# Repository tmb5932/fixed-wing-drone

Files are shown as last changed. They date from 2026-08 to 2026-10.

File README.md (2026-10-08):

# Autonomous RC Plane

A custom flight controller for a fixed-wing RC plane, built from scratch, both the PCB and the firmware. It's built around an ESP32-S3 and runs in-between a standard RC receiver and the servos/esc, giving the plane an onboard brain capable of taking over from the pilot and flying autonomously.

All software is written in ESP-IDF (specifically v5.5). It's a personal challenge to write as much of it as possible without plug-and-play libraries (ESP-IDF's own UART/I2C drivers are fair game), mainly the device drivers and the flight control logic.

## The Goal

The flight control system is a cascade of PID loops: GPS waypoint/heading navigation on the outside, commanding roll/pitch attitude loops on the inside, plus an airspeed loop on the throttle. Target milestones, roughly in order:

- [x] RC pass-through with working sensor drivers (IMU, GPS) and RC I/O
- [x] First flight (manual pass-through, October 3, 2026)
- [ ] Stable autonomous level flight
- [ ] Altitude hold
- [ ] GPS-guided heading / waypoint following (implemented and SITL-tested, not flown yet)
- [ ] Autonomous takeoff and landing

Longer term, the hopes are giving it mission-oriented capabilities like payload release or coordinated flight with a second drone.

## Current Status

The plane had its first flight on October 3, 2026, in manual pass-through mode only. The RC link had signal dropouts during that flight, so that's being debugged before anything autonomous is tried in the air. Since then the firmware has gained an on-board flight event log, a longer signal-loss window, and safer behaviour when the radio drops (see Safety below).

Autonomous mode (attitude stabilization, waypoint following, return-to-home) has only been tested on the bench and in the SITL simulator. The roll/pitch/heading gains come from SITL sweeps and still need real flight tuning.

## Hardware

- ESP32-S3
- ICM-20948 IMU (I2C), roll/pitch/yaw via a Madgwick filter, with its AK09916 magnetometer used for compass heading
- GPS module (UART, NMEA)
- MS4525DO differential-pressure airspeed sensor (I2C)
- Standard PWM RC receiver and servos/ESC, running alongside the ESP32 instead of being replaced by it

Future hardware will hopefully include lidar and a barometer.

### PCB

The firmware currently runs on the **v2.1** board: a custom carrier PCB that an ESP32-S3-DevKitC plugs into. Everything plugs into labeled connectors on the board rather than bare GPIO pins:

- 6 RC receiver inputs (PWM), 6 labeled servo outputs, and primary/secondary ESC signal outputs
- Separate UBEC power inputs for the flight controller and the ESC/servo rail, each with P-FET reverse-polarity protection
- JST-SH (STEMMA QT) connectors for the IMU, the barometer, and a spare QT port for future I2C sensors
- A JST-GH connector for the airspeed sensor, a header for the GPS UART, and connectors for a LIDAR
- An accessory I/O header for things like LEDs, a payload-release servo/relay, etc.
    -   (obviously will require alterations to code, but software is easier to change than hardware is...)

The GPIO-to-connector mapping the firmware uses (CH1_OUT_GPIO etc. in main.c) is defined by the board's pinout, not repeated here.

The KiCad sources in [`kicad/`](kicad) are the **next** revisions, which the firmware hasn't been ported to yet:

- [`kicad/flight-controller/`](kicad/flight-controller): flight controller v3.1, a fully integrated 4-layer board (ESP32-S3 module, ICM-42688-P + BMI088 IMUs, DPS368 barometer, microSD, SBUS/CRSF receiver input, USB-C). Pinout and power details are in [`docs/buses.md`](docs/buses.md), and its design review is in [`kicad/flight-controller/design-review-fixed-wing-drone.md`](kicad/flight-controller/design-review-fixed-wing-drone.md).
- [`kicad/mission-board/`](kicad/mission-board): a second ESP32-S3 payload board (camera, motor drivers, switched outputs, servo driver) that talks to the flight controller over UART.
- [`kicad/uwb-radio-kicad/`](kicad/uwb-radio-kicad): a DWM3000 ultra-wideband radio module for ranging between drones.

## Software Architecture

- **RC input:** 6 channels read via the ESP32-S3's MCPWM capture timers. Interrupt-driven edge timestamping converts rising/falling edges into pulse widths directly, no external library.
- **RC/servo output:** 6 servo channels plus 2 dedicated ESC channels, driven via MCPWM comparators on a 20ms timebase. Input/output channel mapping, per-channel PWM range and reversal are all configurable at runtime.
- **IMU:** ICM-20948 and its AK09916 magnetometer driven with hand-written I2C register reads/writes, fused through a ported Madgwick AHRS filter for roll/pitch/yaw, with a stillness-gated gyro bias calibration at boot.
- **GPS:** UART driver with a hand-written NMEA RMC sentence parser, plus u-blox config commands to quiet down unused sentence types and set a 5Hz fix rate.
- **Airspeed:** MS4525DO driver with a boot-time zero-offset calibration and a low-pass filter on the pressure reading.
- **PID:** a small PID module with integral anti-windup, used for roll, pitch, heading and airspeed.
- **Navigation:** a 10Hz task that steers toward GPS waypoints (or holds the heading the plane had when autonomous engaged) by commanding a bank angle, using the compass heading or, when moving, GPS course over ground.
- **Control loop:** a 100Hz task that reads all RC channels every cycle and switches between manual pass-through and autonomous output based on the mode switch (below 1500us = autonomous), RC signal health and sensor availability.

### Safety

- Autonomous mode is only armed after the mode switch has been seen in manual at least once since boot, and it needs a fresh GPS fix to engage.
- If the RC signal is lost for 1 second, the plane returns to its home point (averaged from GPS at power-on), then spirals down with the motor off. With no GPS fix or no home, it spirals down where it is. If autonomous isn't available at all, it holds the surfaces at trim with the motor off instead of replaying the last stick input.
- After a reboot in the air, manual pass-through comes back first, before anything slow in boot.
- A small flight event log in RTC memory records RC dropouts, signal losses, failsafe transitions and the reset reason of every boot. It survives a reset (not a power cycle) and can be read from setup mode after landing.

### SITL

[`sitl/`](sitl) holds host-side simulators that compile the firmware's own `pid.c` and `gps_math.c` against a simple airframe model, used to tune the attitude and heading gains, with an 80-scenario regression suite. See [`sitl/README.md`](sitl/README.md).

## Build / Flash

Set up ESP-IDF v5.5, then from the project root:

```sh
idf.py build
idf.py flash monitor
```

### Setup mode

Holding the board's BOOT button within 5 seconds of power-on boots into a
setup mode instead of normal flight init: it hosts its own WiFi access point
(`plane-fc-setup` by default) with a local web page for calibrating servo/ESC
PWM ranges and direction, remapping RC/servo channels, capturing trim,
planning the GPS mission, tuning PID gains, setting the airframe mixing mode
and airspeed-hold target, running bench control tests, and reading the flight
event log. Connect to the AP
and browse to `http://192.168.4.1/`. Everything is saved to NVS immediately;
a normal reset (BOOT not held) returns to flight mode with those settings
applied.

## Author

Travis Brown

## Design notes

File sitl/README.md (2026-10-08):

# SITL (software-in-the-loop) for the attitude + nav PIDs

Host-side simulators for tuning `ROLL_PID_CFG` / `PITCH_PID_CFG` (`sitl_sim.exe`) and
`HEADING_PID_CFG` (`nav_sim.exe`) before the plane exists to fly. Both link directly against
`../main/pid.c` and `../main/gps_math.c` — the exact same source files the firmware compiles —
so a gain that behaves well here is a gain that will behave the same way on the real controller.

## Build & run

Requires a host C compiler (this repo's ESP-IDF toolchain is a cross-compiler for the ESP32S3 and
can't build a host executable). On Windows that's MSYS2/mingw-w64 (`mingw32-make`); on macOS/Linux
plain `gcc`/`clang` with `make` works (`make`, `make test`). The binaries are named `.exe` on every
platform.

```sh
cd sitl
mingw32-make
./sitl_sim.exe [k_p] [k_i] [k_d] [duration_s] [initial_disturbance_deg] [--axis=roll|pitch] [--goal=deg] [--i_limit=us] [--noise_deg=stddev] [--servo_rate=deg_per_s] [--seed=n]
python plot.py output.csv     # or: .venv\Scripts\python.exe plot.py output.csv
```

CLI defaults are `k_p=10 k_i=0 k_d=0`, 5s, starting 20° off level, roll axis, goal 0° (i.e. recover
to level — the firmware's only behavior until something calls `set_goal_roll_deg`/`set_goal_pitch_deg`).

Or use `python gui.py` (`.venv\Scripts\python.exe gui.py`) for an interactive version: pick an axis,
enter gains, hit Run, see the plot update immediately, with the previous run kept as a faint
reference line so you can see the effect of a change rather than comparing two separate plot windows
from memory. (The reference line clears when you switch axes — roll and pitch use different plant
dynamics now, so overlaying them wouldn't mean anything.) The noise/servo-rate/seed fields live in
their own "Sensor / actuator realism" group, separate from the tuning fields, since they describe
imperfections in the simulated world rather than the controller itself.

`nav_sim.exe` simulates the outer waypoint-following loop added in `nav.c`: it cascades
`HEADING_PID_CFG` into the same roll-attitude loop as `sitl_sim.exe` (reusing its plant/actuator
model), flying a simple coordinated-turn/flat-earth world model toward one or more waypoints.

```sh
./nav_sim.exe [--target_bearing=deg] [--target_dist_m=m] [--wp=lat,lon (repeatable, overrides target_bearing/dist)] [--start_lat=deg] [--start_lon=deg] [--heading0=deg] [--airspeed=mps] [--duration_s=s] [--heading_kp=] [--heading_ki=] [--heading_kd=] [--heading_ilimit=] [--roll_kp=] [--roll_ki=] [--roll_kd=] [--roll_ilimit=] [--roll_noise_deg=] [--heading_noise_deg=] [--servo_rate=deg_per_s] [--seed=n]
python plot_nav.py nav_output.csv
```

With no `--wp`, it generates a single waypoint at `--target_bearing`/`--target_dist_m` from the
start position, which is usually more convenient for gain-sweeping than hand-picked lat/lon pairs.

`mingw32-make test` builds both binaries and runs `tests/run_tests.py`, an 80-scenario regression
suite against the current firmware gains (clean step responses, noise-robustness sweeps, and
waypoint-mission edge cases) — exits nonzero if anything fails.

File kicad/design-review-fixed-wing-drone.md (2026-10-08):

> **Superseded.** This is the original review of flight controller **v3.0** (2026-09-11), kept for history. Most of its findings were fixed in v3.1 (for example, the ESP32's LDO is now the XC6220 `U4`, and USB-C now has ESD protection). The current review is [`flight-controller/design-review-fixed-wing-drone.md`](flight-controller/design-review-fixed-wing-drone.md), and the current pinout is [`../docs/buses.md`](../docs/buses.md).

# Design Review — Autonomous Fixed-Wing Drone Flight Controller

**Board:** `fixed-wing-drone` v3.0 (4-layer, 91.0 × 61.5 mm, 78 footprints)
**Review date:** 2026-09-11
**Tooling:** kicad-happy analyzer suite (`kicad`, `emc` skills) v2.2.1 + manual raw-file verification
**Reviewer basis:** static analysis + direct `.kicad_sch`/`.kicad_pcb` inspection. **No component datasheets were available** (no `datasheets/` directory, no distributor API keys configured) — see *Verification Basis* below. All pin-level and electrical claims in this report are **consistency checks against the schematic/PCB themselves, not manufacturer-datasheet-verified**, except where explicitly marked "domain knowledge, unverified."

## Verdict: **Conditionally ready — fix 3 items before fab, 1 before flight test**

The board is structurally sound (0 unrouted nets, 4-layer stackup with dedicated ground/power planes, clean gerber export) but has one thermal margin problem serious enough to affect flight reliability, a hard sourcing blocker for ordering, and a stale-file hygiene issue worth resolving before anyone edits this design again. Nothing found is a "board is dead on arrival" bug (no swapped IC pins were found in the ICs checked), but the LDO thermal issue below is not cosmetic — it affects the rail that powers the flight computer itself.

---

## Blockers (fix before fab)

| # | Severity | Finding | Evidence |
|---|---|---|---|
| 1 | **HIGH — thermal/safety** | U5 (AP2112K‑3.3, SOT‑23‑5) regulates 5V→3.3V for the **ESP32‑S3 flight computer's own supply** (`ESP_3V3`). At an assumed WiFi‑active load current, estimated Tj ≈ 124 °C against a 125 °C absolute max — **2 °C margin**. The package has no thermal pad (θJA ≈ 250 °C/W) and a 1.7 V dropout, so *any* sustained current draw above a few tens of mA runs it hot. ESP32‑S3 WiFi TX bursts commonly pull 300–500 mA. | `analysis/2026-09-11_1844/thermal.json` (rule TS‑002); schematic `U5` on `fc_ldo.kicad_sch`/`esp32s3.kicad_sch` net `ESP_3V3`. **Caveat:** the load current behind this estimate is a heuristic default, not a measured/derived figure (schematic power-budget module returned `estimated_load_mA: 0` for this rail — see Gaps below) — so treat 124 °C as directionally right, not exact. Given ESP32-S3's known TX current spikes, this is very plausibly correct or optimistic, not pessimistic. |
| 2 | **HIGH — sourcing (pre-fab gate)** | Only 7 of 30 unique parts (23%) have an MPN populated in the schematic. Rule `SS-001`: "Sourcing blocker: BOM has <50% MPN coverage. Board is not pre-fab ready." **Note:** a separate hand-fabrication BOM exists (`production/FULL_POP_..._bom.csv`) with LCSC part numbers for nearly every part — the gap is that this data lives in a CSV outside the KiCad schematic, not in the symbol properties the analyzer reads. | `analysis/2026-09-11_1844/schematic.json` (`bom_coverage.mpn_pct=21.9`); cross-checked against `production/FULL_POP_Autonomous_Fixed_Wing_FC_v3.0_bom.csv`, which does have LCSC numbers for 27 of the ~30 lines. |
| 3 | **MEDIUM — housekeeping / design-sync risk** | `airspeed.kicad_sch` and `lidar.kicad_sch` exist in the project directory but are **not instantiated anywhere in the sheet hierarchy** — verified by grepping every `.kicad_sch` for `(sheet ...)` includes; neither file is referenced from any reachable sheet. **This is not a missing-sensor bug**: the real, wired design already has airspeed and lidar interfaces — `J15` ("Airspeed I2C") and `J8` ("LIDAR I2C") both live in `external_sensors.kicad_sch`, which *is* in the hierarchy, and both appear in the production BOM/position files. `lidar.kicad_sch`'s components (`J8`, `L2`) are literal duplicates of what's already wired in `external_sensors.kicad_sch`. `airspeed.kicad_sch`'s components (`J12`, `L3`) do **not** appear anywhere in the reachable hierarchy at all — this looks like an earlier on-board-sensor-IC design draft that was superseded by the simpler external-connector approach and never deleted. Recommendation: delete both orphan files, or if there was a reason to move to an on-board airspeed sensor with the `L3` filtering shown in the orphan file, wire it in deliberately. Left as-is, these files will confuse the next person who edits the hierarchy or runs ERC sheet-by-sheet. | `grep -oE '"[a-zA-Z_]+\.kicad_sch"' *.kicad_sch` cross-reference (see transcript); `analysis/2026-09-11_1844/schematic.json` `sheets[]` (11 reachable sheets, excludes airspeed/lidar). |

## Fix before flight test (not fab-blocking)

| # | Severity | Finding | Evidence |
|---|---|---|---|
| 4 | WARNING | **VBUS on J13 (USB‑C) has no decoupling and no ESD/TVS protection.** J13 is marked DNP (hand-solder), but if it's ever populated for field debugging, an unprotected USB‑C VBUS on a vehicle that operates outdoors is a real ESD exposure path into the 5V domain. | `schematic.json` rules `UC-001`, `UC-002`. |
| 5 | WARNING | 18 of 18 external/inter-board connectors (servo I/O, ESC I/O, GPS/UART, I2C sensor headers, SPI, debug headers) show **zero ESD protection** (`EP-AUD`, "none coverage" on all). For a design with cables running out to servos/ESCs/GPS in an airframe subject to field handling and connector mating/unmating, this is worth a deliberate risk decision rather than a silent gap — TVS diodes on at least the RC receiver input (J7) and any GPS/telemetry cable are the highest-value additions. | `schematic.json`, 18× `EP-AUD` findings. |
| 6 | INFO (assess as MEDIUM in practice) | J13 (USB‑C receptacle, 16‑pin **SMD**, fine-pitch) is marked `(dnp yes)` — i.e., intended for hand assembly, not JLCPCB SMT placement. Hand-soldering a 16-pin SMD USB-C receptacle without hot air/reflow is failure-prone (bridged VBUS/GND shield pins, tombstoned shield tabs). All the *other* DNP parts (J1–J9, J16, J19, J20, J22 — the servo/ESC/UBEC pin headers, and J7 the RC receiver connector) are through-hole 3‑pin headers, where DNP-for-hand-solder is completely normal/expected. J13 is the odd one out. Confirm this is intentional. | Raw `esp32s3.kicad_sch:3529-3537` — `(dnp yes)(in_bom yes)(on_board yes)` on the `USB_C_Receptacle_USB2.0_16P` symbol; cross-checked against `production/*_desig.csv` (J13 present, position-only) vs `*_bom.csv` (J13 absent — no LCSC part ordered for it). |
| 7 | WARNING (EMC) | EMC pre-compliance risk score **52/100** (moderate-high). Drivers: low ground-plane fill ratio (F.Cu 49%, B.Cu 44% — confirmed directly from zone fill data, not just the EMC heuristic), missing stitching vias at ~20+ signal layer transitions (SPI/I2C/UART buses to the IMUs, barometer, SD card, UWB radio, inter‑ESP link), SCK routed on an outer layer near connectors J10/J15, and one connector (J13) with no local filtering. See EMC section below. | `analysis/2026-09-11_1844/emc.json`; `pcb.json` zones (fill_ratio 0.494/0.441 for GND on F.Cu/B.Cu). |
| 8 | INFO | PCB has an **unfilled zone on net 0** ("no net") spanning all 4 copper layers (`is_filled: false`, no `fill_ratio`). If this is a deliberate keepout/rule area, fine; if it's a stale zone from editing, refill or delete it — stale zone fill data also means any "copper presence" analysis over that area is unreliable until refilled. | `pcb.json` `zones[]` entry with `net=0`, all layers, `is_filled=false`. |

## Positive findings (verified directly, not just "no finding raised")

- **Routing is complete**: 0 unrouted nets across 84 nets, 632 track segments, 178 vias on a 4-layer stack.
- **Custom DRC rule exists and is architecturally sound**: `fixed-wing-drone.kicad_dru` enforces ≥2mm clearance between `/FC_5V` (flight-computer power) and `/actuator_io/esc_io/SERVO_5V` (servo power) — a deliberate isolation choice so servo-current transients/brownouts don't couple into the FC's own supply. Verified both nets do have separate zone polygons on the shared `In2.Cu` (Pwr.Cu) inner layer as the rule implies. **Not independently verified**: actual DRC pass/fail against this rule — `kicad-cli` is not installed in this environment, so native DRC could not be run (see Gaps).
- **ESP32-S3 EN (reset) circuit is correctly designed** — I initially flagged this as a possible false-positive-worth-checking because the analyzer's `PU-001` rule reported "U1 pin EN missing pull-up resistor." Direct pin-net trace shows this is a **false positive**: `EN` is pulled up through `R7` (10k) to `ESP_3V3`, decoupled by `C12` (1µF) and `C14` (100nF), with `SW1` (TS‑1088 tactile switch) providing a manual reset-to-GND path — a textbook-correct ESP32 EN circuit. (`esp32s3.kicad_sch`, `ic_pin_analysis` for U1 pin 3.)
- **U3 (backup IMU) INT1–INT4 "missing pull-up" findings are also false positives/non-issues** — direct inspection shows all four interrupt pins are explicitly marked `NO_CONNECT` (deliberately unused), not floating inputs needing a pull-up. The `PU-001` heuristic doesn't distinguish sensor-output interrupt pins from bus inputs; both flagged instances here are noise, not real findings.
- **Gerber export is clean**: extracted and ran the gerber analyzer against the `production/FULL_POP_..._v3.0.zip` package (15 files: 4 copper layers incl. 2 inner planes, both silkscreens, both masks, both paste, edge cuts, PTH/NPTH drill + drill maps) — 0 findings (no missing layers, no alignment issues, no drill classification problems).
- **Component/footprint reconciliation is clean**: 75 schematic components vs 78 PCB footprints; the +3 is fully accounted for by 3 mounting holes (`M2`, no schematic symbol expected) — no unexplained extras.
- **DNP strategy for THT headers is sound**: all pin-header connectors (servo/ESC/UBEC-input, RC receiver) are marked DNP for SMT assembly with position data retained — standard "assembly house places SMD, builder hand-solders THT headers" practice, not a build-blocking omission.

## Power Tree

```
Battery/BEC (off-board) ──> J20 "FC UBEC Input" ──> FC_5V ─┬──> U5 AP2112K-3.3 ──> ESP_3V3 ──> U1 (ESP32-S3-WROOM-1)
                                                              └──> U6 AP2112K-3.3 ──> SENSOR_3V3 ──> U2/U3 (IMUs), U7 (barometer), external sensor headers
Servo/ESC power path: separate SERVO_5V net (2mm-isolated from FC_5V by custom DRC rule), routed to J19/J22 (ESC1/ESC2) and servo connectors via In2.Cu plane
```

- Two identical AP2112K‑3.3 LDOs (U5, U6) in SOT‑23‑5, no thermal pad, both dropping 5V→3.3V (1.7V dropout each). Only U5's rail was flagged by the thermal analyzer (it's carrying the higher-current MCU load); U6's sensor rail load is presumably lower but uses the *same* thermally marginal topology — worth a sanity check on total sensor-rail current (2× IMU + barometer + any bus pull-ups) if more sensors get added later.
- Regulator Vout for both was derived via `fixed_suffix` (deterministic — the "-3.3" in the part number), not a feedback-divider calculation, so this is a solid data point, not a heuristic guess.
- No PG (power-good) signal traced for either regulator — `PS-001` notes PG status is unknown without a datasheet (AP2112K does not have a PG pin per its part family — this is expected/non-issue, but unverified here since no datasheet was pulled).

## EMC Pre-Compliance Summary

Risk score: **52/100** (moderate-high), 55 findings (3 error, 36 warning, 16 info), trust level **low** (0% datasheet-backed — expected, since no datasheets were synced; findings are topology/heuristic-based).

Top drivers, all corroborated against raw PCB data (not just the EMC heuristic layer):
- **GP‑001/GP‑004** — reference-plane gaps under signal traces + low GND fill ratio, confirmed directly (F.Cu GND zone fill 49.4%, B.Cu 44.1%).
- **RP‑001** — 20+ signal nets (SPI to both IMUs/barometer/SD/UWB, I2C, inter-ESP UART, ESP32 BOOT strap) change layers without a nearby stitching via, weakening return-path continuity — this is the largest single finding category and the most actionable (add stitching vias near layer transitions on these nets).
- **IO‑001** — no EMC filtering near J13 (consistent with finding #4 above).
- **CK‑001/CK‑003** — the SPI `SCK` clock is routed on an outer layer and passes near connectors J10 and J15 — a radiated-emissions risk at harmonics of the SPI clock rate.

## Thermal Hotspot Summary

Score 85/100, 1 error + 4 info findings, all centered on **U5** (see Blocker #1). Four MLCCs (C6, C7, C10, C11 — the very decoupling/bulk caps for this rail) sit within 3–7mm of the hot regulator; at the estimated 124°C ambient-adjacent temperature, X7R caps lose ~15%+ effective capacitance, compounding the margin problem on the rail that's already running hot.

## SPICE Simulation

**Not run — no simulator installed.** Checked `ngspice`, `ltspice`, `xyce` via `which`; none present in this environment. This is a disclosed gap, not a silent skip. If a simulator becomes available, the highest-value targets detected by the schematic analyzer are the RC filters (10 detected) and the two LDO topologies — worth simulating the AP2112K‑3.3 loop stability/transient response given the thermal finding above.

## Component Lifecycle Audit

**Not run — no network/distributor API keys configured** (checked `DIGIKEY_CLIENT_ID`, `MOUSER_SEARCH_API_KEY`, `ELEMENT14_API_KEY`; none set). Disclosed gap. LCSC lookups (no auth required) were also not attempted in this pass — recommend running `lifecycle_audit.py --only lcsc` separately using the LCSC part numbers already present in `production/FULL_POP_..._bom.csv`, since MPN coverage in the schematic itself is too low (23%) for the audit to be useful as-is.

## Datasheet Coverage / Verification Basis

**No `datasheets/` directory existed; no distributor API keys were configured**, so no automated datasheet sync was possible in this environment. `DS-002` fired (schematic analyzer). Consequently:
- All pin-function, pin-mapping, and "matches datasheet" claims in this report are **schematic-internal consistency checks**, not datasheet-verified — the EN circuit and IMU NC-pin findings above were confirmed by tracing the schematic's own netlist, not by checking against an AP2112K-3.3 or IMU datasheet.
- No IC in this design was pin-verified against a manufacturer PDF. The ESP32‑S3‑WROOM‑1 module footprint/pinout, the two IMUs (U2/U3, both unidentified generic values — "Primary IMU"/"Backup IMU" — no MPN in the schematic beyond the production BOM's LCSC numbers C1850418/C194919), and the DPS368-family barometer (U7) were **not** opened against their datasheets in this pass.
- Recommendation: run `sync_datasheets_lcsc.py` against the LCSC part numbers already present in the production BOM CSV (even though they're not in the schematic's MPN properties) before the next review pass — this closes both the datasheet gap and the sourcing-gate blocker (#2) in one step, since those numbers are already known-good enough to have been used for a real fab run.

## Gaps / Not Performed (explicit disclosure)

| Item | Status | Reason |
|---|---|---|
| Datasheet sync / per-IC datasheet verification | Not performed | No `datasheets/` dir, no distributor API keys in this environment |
| SPICE simulation | Not performed | No ngspice/LTspice/Xyce installed |
| Component lifecycle audit | Not performed | No network-authenticated distributor API keys (LCSC no-auth path was not attempted this pass) |
| Native KiCad DRC/ERC (`kicad-cli`) | Not performed | `kicad-cli` not on PATH in this environment; relied on the kicad-happy static analyzers' ERC/DRC-equivalent checks instead, which is a narrower rule set than KiCad's own DRC/ERC engine |
| Full per-IC Deep Review pass (all ICs against datasheets) | Partially performed | Only U1 (EN circuit) and U3 (INT pins) were pin-traced in depth, both to resolve/triage specific analyzer findings; U2, U6, U7, and the ESP32-S3's full pinout were not individually walked pin-by-pin against a datasheet due to the datasheet gap above |
| Prior design review delta | Not applicable | No earlier `*review*.md`/`*design-review*.md` file existed in the project directory to diff against |
| PDF reference design comparison | Not applicable | No PDF reference designs or datasheet application circuits found in the project tree or sibling directories (`../docs` contains only `buses.md`, a markdown note, not a schematic PDF) |
| companion `uwb-radio-kicad/` project | Out of scope | Separate KiCad project (its own `.kicad_pro`), not part of `fixed-wing-drone.kicad_pcb`; noted for awareness only, not reviewed |

---

*Full analyzer JSON outputs are cached under `analysis/2026-09-11_1844/` (schematic.json, pcb.json, cross_analysis.json, emc.json, thermal.json, gerber.json) for anyone who wants to re-query specific findings.*

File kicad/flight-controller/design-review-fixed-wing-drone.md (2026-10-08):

# Autonomous Fixed-Wing Drone Flight Controller — Design Review

**Project:** `fixed-wing-drone` v3.1 (KiCad 10.0.1, 12 hierarchical sheets, 4-layer PCB, 91.0 × 61.5 mm)
**Date:** 2026-10-03
**Baseline:** commit `ddca75b` ("progress on v1 of mission board"). "Changes since `ddca75b`" lists everything changed after that commit.
**Location:** `kicad/flight-controller/`

## Review process

1. **Four independent reviews.** Two schematic reviewers and two PCB reviewers each did a full review without seeing each other's work, and without seeing earlier review documents. Between them they raised 35 distinct issues.
2. **Independent verification.** A separate verifier checked every claim against KiCad's netlist, the PCB geometry (pcbnew Python), the manufacturer datasheets (Torex XC6220, AOS AO3407A, TDK ICM-42688-P, Bosch BMI088, Espressif ESP32-S3, ST USBLC6-2) and live JLC/LCSC catalog lookups. Results: 21 confirmed, 12 partially confirmed with corrected severity, 0 pure false positives, and two conflicts between reviewers resolved.
3. **Iterative checks after each round of fixes.** After each round I diffed the netlist and PCB footprints, ran `kicad-cli sch erc`, and ran `kicad-cli pcb drc --schematic-parity --refill-zones`. KiCad's own netlist is treated as ground truth for connectivity.

Not re-run this pass: the kicad-happy EMC, thermal and SPICE analyzers. The changes were targeted and were verified directly instead (see "Review limits").

## Verdict

**Ready for fab.** Round 2 (below) added no must-fix items on the flight controller itself. The one cross-board item, the inter-ESP connector (J11 ↔ mission-board J18), has since been fixed on the mission board.

Current state, with zones refilled:

| Check | Result |
|---|---|
| ERC errors | 0 |
| ERC warnings | 1, cosmetic: J7 library-symbol mismatch |
| DRC unconnected items | 0 |
| DRC clearance errors | 0 |
| DRC remaining errors | Only J13 pads A1/B12 "starved thermal" (accepted, see below) |
| Schematic ↔ PCB parity | In sync. Only board-only items (FID1–3 fiducials, M2 mounting holes) are flagged. |

## Changes since `ddca75b`

### Schematic and netlist

| Change | Detail |
|---|---|
| **ESP32 module variant** | U1 `ESP32-S3-WROOM-1-N16R8` (C2913202) → `-N16R2` (C2913205). The 2 MB **quad** PSRAM frees GPIO35/36/37; on R8/R16V parts these pins are wired to the octal PSRAM. The N16R2 is also rated −40–85 °C, versus −40–65 °C for the N16R8. **Do not substitute an R8 part.** |
| **Dedicated microSD SPI bus** | SD_SCK = IO35 (U1.28), SD_MOSI = IO36 (U1.29), SD_CS = IO37 (U1.30), SD_MISO = IO8 (U1.12). Card1 is no longer on the shared sensor bus. R28/R29/R30 (10k pull-ups to ESP_3V3) added on SD_MISO/SD_CS/SD_MOSI. |
| **USB data ESD** | D8/D9 (2× ESD5Z5.0T1G) replaced by U5 USBLC6-2SC6 (C7519). Pins 1/6 = D+, 3/4 = D−, 2 = GND, 5 = VBUS. The VBUS net was renamed `/esp32s3/USB_VBUS`. |
| **FC 5 V input** | Q1/R8 (P-FET reverse-polarity stage) removed. D5 (B5819W) already blocks reverse current. J20 pin 1 is now GND, so J20 = GND / V+ / GND and the plug can go in either way round. |
| **Servo rail** | Q2/R10 removed. The FET's thermal margin was inadequate for six servos, and it gave no protection against a flipped centre-V+ servo plug. J22 pin 2 now feeds SERVO_5V directly. C20 (22 µF / 25 V 0805, C45783) added on SERVO_5V near J7. |
| **U4 input cap** | C18: 10 µF / 6.3 V 0603 (C1691) → 22 µF / 25 V 0805 (C45783). The old part derated to roughly 3–4 µF at 5 V, which falls in the XC6220's "CIN 4.7 µF needs CL 47 µF" stability row. |
| **I2C pull-ups** | R20/R21: 6.8k → 4.7k (C25900), for margin with three cabled I2C devices. |
| **UWB power** | J10 pin 1: SENSOR_3V3 → FC_5V through ferrite L3 (BLM18PG121SN1D). The UWB board must carry its own 3.3 V LDO (see "Cross-board dependency"). |
| **BOM fixes** | J8 LCSC C234195 (not in JLC catalog) → C17617036. R26/R27 (330 Ω, RC_TX/RC_SBUS series resistors) given LCSC C25104. Without a number, JLC would have skipped them and left the RC lines open. R24/R25 (33 Ω 1206 IR LED feed) given C5759775 (0.75 W). ESP32 sheet title corrected to N16R2. |

### PCB

| Change | Detail |
|---|---|
| EN reset filter | C12/C14 moved from beside SW1 (~47 mm away) to 4.0/4.4 mm from U1 pin 3. R7 is 1.6 mm from the pin. |
| USB-C position | J13 moved to x = 101.875. Its "PCB edge" line is now flush with Edge.Cuts; it was previously recessed ~0.75 mm. D+/D− rerouted. |
| U5 jumper groups | `jumper_pad_groups` (1,6) and (3,4) are present. **Note:** the stock `SOT-23-6` footprint does not carry these, so updating footprints from the library strips them and brings back two false "unconnected" DRC errors. Consider a project-local copy of the footprint. |
| EPAD vias | 9 × 0.3 mm GND vias, one in each pad of U1's 3×3 EPAD (Espressif land pattern). |
| MISO | The 5 inner-layer MISO segments beside the BMI088 moved from In1 (GND) to In2 (Pwr). The In1 GND plane under U3 is unbroken. |
| SBUS/RC TVS | D6/D7 moved from ~32 mm away to 5.0/4.7 mm from J7 pins 1/4. |
| Fiducials | `REF**` ×3 renamed FID1 (142.25, 82.25), FID2 (118.25, 96.25), FID3 (161.25, 118.75). Their reference text is on F.Fab, not silkscreen. |
| Silkscreen | Board text corrected to "v3.1". |

## Review findings and disposition

Severities are the verifier's corrected ratings.

### Fixed
| Finding | Severity |
|---|---|
| SERVO_5V had no capacitance (receiver brown-out risk) | HIGH → C20 22 µF added. The user's decision was to skip bulk capacitance, because v2.0 drove six servos with no caps (see "Accepted"). |
| Q2 SOT-23 P-FET undersized for servo current | MEDIUM → removed |
| EN RC 47 mm from module | MEDIUM → moved |
| USB-C recessed 0.75 mm | MEDIUM → fixed |
| UWB powered from the IMU rail (SENSOR_3V3) | MEDIUM → moved to FC_5V via ferrite + LDO on the UWB board |
| C18 bias derating / XC6220 stability | LOW → 22 µF 25 V 0805 |
| ESP32 EPAD had no vias | LOW → 9 vias |
| MISO slot in In1 GND under BMI088 | LOW → moved to In2 |
| SBUS/RC TVS far from J7 | LOW → moved |
| I2C pull-ups weak for cabled bus | LOW → 4.7k |
| Q1 redundant with D5 | LOW → removed. J20 pinout made symmetric. |
| J8 LCSC not orderable; R24–R27 missing LCSC | LOW/HIGH-impact → fixed |
| R24/R25 1206 overloaded (0.33 W) by a shorted LED cable | LOW → 0.75 W part (C5759775) |
| Duplicate `REF**` fiducial designators | LOW → FID1–3 |
| ESP32 title said N16-R8 | INFO → fixed |

### Accepted / not changed (with rationale)
| Finding | Rationale |
|---|---|
| No bulk cap on SERVO_5V | The v2.0 board ran six servos with no caps. One 22 µF ceramic was added as a compromise. If receiver brown-outs or failsafes appear (check receiver telemetry: RX voltage, frame loss), add a 220 µF polymer (e.g. C22395163, 6.3 × 5 mm). |
| No pull-ups on the 5 sensor-bus CS lines | No board space. Handled in firmware (see "Firmware to-do"). |
| UWB shares the sensor SPI bus; no series resistors on J10 | Accepted. The ESP32-S3 has only two user SPI hosts, and the SD card uses the other one. Power is isolated (ferrite + separate LDO). |
| J14 GPS pinout isn't Pixhawk DS-009 | Not a defect. J14 (SDA, GND, RX, TX, 5V, SCL) matches the RDQ BN-880 module ("SDA, GND, TX, RX, VCC, SCL") with TX/RX already crossed, so a straight-through cable works. |
| No TVS on FC_5V | Skipped. The LDOs' absolute max is 6.0–6.5 V. Relies on a correctly set UBEC and D5. Hot-plug ringing risk is low because the servo lead stays plugged in and the BEC ramps with the ESC. |
| No 10 µF at microSD; C13 is ~7 mm from Card1 VDD | C13 cannot move closer. C10 (22 µF) is on ESP_3V3. Revisit only if SD write errors or brown-outs appear. |
| No 100 nF at U5 pin 5 | No space. C17 (10 µF) is ~5 mm away on the same net; ST lists the cap as best practice only. |
| Inner-zone clearance 0.5 mm (via anti-pads merge into slots beside U1) | Not changed. Optional improvement: 0.2–0.25 mm, then refill. |
| J13 A1/B12 starved thermal (DRC) | Accepted by the user. The pads are connected to GND, just with fewer spokes than the rule requires. |
| No battery voltage/current sense | No free ADC1 pin. Plan an I2C power monitor (e.g. INA226-based module) on the existing bus. |
| ESC_OUT1/2 no pull-downs; ICM-42688 FSYNC NC; BMI088 INT pins NC | INFO/LOW. ESCs need a valid pulse train to arm. INT2 defaults to an open-drain output. The BMI088 is polled. |
| SD pins use the GPIO matrix rather than native FSPI IO_MUX | INFO. Fine for SD at ≤20 MHz. |

## Round 2 review (2026-10-03, after all fixes)

**Method.** Four new blind reviewers (two schematic, two PCB) worked without access to round 1 or to this document. They raised 32 claims, and an independent verifier checked each one against the netlist, the PCB geometry, the datasheets and the LCSC/JLC pages. Result: no CRITICAL or HIGH issues.

**Fixed in round 2**

| Item | Fix |
|---|---|
| J9 (IR LED connector) had no LCSC number | **C161691** (BM03B-GHS-TBT), the same part as J11. It matches the footprint exactly. |
| D5 Notes field said "ESC1 UBEC diode" | Changed to "FC UBEC input diode (J20 -> FC_5V)" |
| TP1–TP10 appeared in the BOM and placement file with no part | Excluded from BOM and position files, in both schematic and PCB |
| J19 pin 2 (NC) labelled "5V" on silk | Relabelled "NC" |
| "91mm" / "61.5mm" text would print on the board | Moved from F.Silkscreen to Dwgs.User |
| 32 silk texts had 0.1 mm stroke | Raised to 0.15 mm. The silk-overlap and silk-over-copper counts did not change. |
| Mounting holes all named `M2` | Renamed H1–H3 (owner) |

**Cross-board item, fixed on the mission board.** FC J11 is 1 GND / 2 TX / 3 RX, while the mission-board J18 was 1 TX / 2 RX / 3 GND, and its description calls for a straight-through cable. With a 1:1 cable, the mission-board TX would be driven into FC GND and FC RX would be held low. The mission-board J18 is now 1 GND / 2 RX / 3 TX (confirmed in its netlist on 2026-10-08), so a 1:1 cable crosses TX and RX correctly.

**Sourcing: resolved.** The jlcsearch mirror of JLC's library proved incomplete and stale. It reported C25531 as missing, C161692 at 2 in stock and C378970 at 162. The owner checked JLC's own parts pages on 2026-10-03 and found C25531 present, **C161692 (J15) at ~14k** and **C378970 (J10) at ~23k**. Do not rely on jlcsearch for stock. DPS368 (C3232508) was reported at ~285; confirm it on JLC as well.

**Should fix (cheap; layout or placement work, left to the owner)**
- **ICM-42688 U2 pin 9 (FSYNC):** the datasheet says to connect it to GND if unused. Floating is harmless by default: at reset it is INT2, open-drain, active-low. To fix, tie pins 9, 10 and 11 to GND with an F.Cu stub. **Pad 8, next to pin 9, is SENSOR_3V3. Do not bridge it.**
- **ESC_OUT1/ESC_OUT2:** no pull-downs, so the outputs float during boot. Fix: 100k (C25741) to GND on the connector side of R22/R23.
- **C19 → C15850** (10 µF 25 V 0805). This is optional, because C10 (22 µF, 5.9 mm from U4) already gives enough output capacitance.
- **D3/D5 → DSS24 (C2923950, SOD-123FL, 2 A).** This adds margin on FC_5V; the peak load is ~0.8 A against the B5819W's 1 A rating. It is nearly a drop-in on the SOD-123 land.
- **Servo rail feed:** add 4–6 vias at J22 (there are 5 now), and order **1 oz inner copper**. JLC's default inner copper is 0.5 oz. A solid zone connection on the servo-header 5 V pins would help current capacity but makes hand-soldering harder.
- **GND island near Card1:** the F.Cu GND island around Card1 and the 330 Ω resistors (~43.5 mm²) has a single stitching via. Add 2–3 more.
- **Plane-split crossings (optional):** B.Cu servo/SBUS traces cross the Pwr.Cu FC_5V/SERVO_5V split. This is an EMI concern only. Move the crossing segments to F.Cu.
- **"Power Plane Split" silk:** the hatch line at x = 164.5 runs over the D7 pads. It is cosmetic, because the fab clips silk on pads.

**Re-confirmed as accepted.** The facts match the owner's assumptions for all of these: CS pull-ups, microSD bulk cap, FC_5V TVS, MISO on Pwr.Cu, the servo bulk cap, the I2C module pull-up meter check, and the J13 starved thermal. The starved thermal is a KiCad DRC error only and does not block fab. U4's thermal estimate is Tj ≈ 85 °C at 40 °C ambient against a 125 °C limit, which is adequate.

**Accepted failure mode to record.** The UWB module shares the IMU/barometer SPI bus through an off-board cable, with no series resistors and no ESD protection. A harness fault (MISO shorted, or a stuck UWB driving MISO) takes out **both IMUs and the barometer at once**.

**Other notes**
- **R1 back-power:** if the receiver is powered (SERVO_5V) while FC_5V is off, it back-powers the ESP32 at ~8 mA through R26/R27 and the clamp diodes. Benign.
- **R2 cables:** the LIDAR model is still unknown. Benewake parts order SDA/SCL differently from J8's Pixhawk order, so build the cable to suit. The BN-880 may ship with a 1.0 mm SH lead, which would need a GH adapter.

Minor, still open:
- TP1/TP9 "non-mirrored text" warnings are on B.Fab, which is not printed. Harmless.
- J7 ERC library-symbol mismatch. Cosmetic.

## Cross-board dependency: UWB radio

J10 pin 1 now supplies **5 V** (FC_5V via L3). The DWM3000 is a 3.3 V-only part. The UWB board (`../uwb-radio-kicad/`) **must** have its own 3.3 V LDO (e.g. AP2112K-3.3, 1 µF in/out) plus 10 µF + 100 nF at the module VDD pins. Do not connect an older UWB board without that LDO; it would destroy the DWM3000. As of 2026-10-08, the UWB schematic has its LDO drawn in: CN1 pin 1 (5V) feeds U2 (XC6220B331PR-G), whose 3.3V output supplies the DWM3000. Verify that board's decoupling before ordering both. Also consider labelling J10/CN1 pin 1 "5V" on both silkscreens.

## Firmware to-do for bring-up

- **PSRAM:** `sdkconfig` set for **2 MB quad** PSRAM (N16R2), not octal.
- **SD card:** SPI on GPIO35 (SCK), 36 (MOSI), 37 (CS), 8 (MISO), on its own SPI host.
- **Sensor-bus chip selects:** at the very start of `app_main`, before any SPI init, drive all five CS lines (IMU1_CS, IMU2_ACCEL_CS, IMU2_GYRO_CS, BAROMETER_CS, UWB_CS) as outputs high, with internal pull-ups enabled.
- **IMUs:**
  - BMI088: the accelerometer starts in I2C mode. Do a dummy read on CSB1 (e.g. ACC_CHIP_ID) to switch it to SPI.
  - ICM-42688-P: set `UI_SIFS_CFG = 11` to disable its I2C interface.
- **Barometer:** DPS368 supports SPI mode 3 only.
- **UWB:** use a slow SPI clock for DWM3000 init, before its PLL locks. The bus speed has to switch per device.
- **UART0 / RC link:** the RC link is on UART0 (GPIO43/44), so the ROM boot log is sent to the receiver. Suppress it (eFuse/GPIO46), or move the console to USB-Serial-JTAG.
- **SBUS:** enable UART RX inversion.
- **GPS (BN-880):** default 38400 baud. Detect the compass chip at bring-up (HMC5883L vs QMC5883L clone). Start I2C at 100 kHz.

## Ordering notes (JLCPCB)

- **Panel rails:** the ESP32 antenna overhangs the top edge by ~6.2 mm, by design. Request rails on the other edges only.
- **Finish:** ENIG recommended, for the 0.5 mm-pitch LGA sensors. `copper_finish` is currently unset in the project.
- **Stackup:** the file declares 0.1 mm prepreg with 35 µm inner copper. Select JLC's standard 4-layer stackup when ordering. Only the short USB pair is impedance-sensitive, and only at full speed.
- **Placement file:** check polarity and rotation in JLC's CPL preview, particularly for the polarized/oriented parts (diodes, LEDs, USBLC6, LGA sensors).
- **Hand-soldered parts:** J1–J7, J19, J20 and J22 are DNP through-hole headers. Check that standard JR/Futaba servo plugs physically seat in the KK-style footprints.

## Datasheet folder housekeeping

- `datasheets/imu_DPS368_datasheet.pdf` is actually the **BMI088** datasheet. Rename it.
- There is no local XC6220 (U4) datasheet. `C51118_…pdf` is a duplicate of the AP2112K datasheet (U6's LCSC part).

## Review limits

- The kicad-happy EMC, thermal and SPICE analyzers were not re-run on the final state. The earlier pass's results (thermal U6 Tj ≈ 41 °C; U4 manual estimate ≈ 69–80 °C worst case; SPICE subcircuits passing) predate this round. They did include Q1/Q2, which are now removed.
- No component lifecycle audit (no distributor API keys).
- No gerber or drill review. Re-export the fab package from the final board.
- External module behaviour was not verified: receiver signal voltage, BN-880 pull-up voltage (it should be 3.3 V, not 5 V; check with a meter), LIDAR minimum supply voltage (FC_5V is ~4.5–4.7 V after the Schottky).

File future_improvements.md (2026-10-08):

# Future Improvements

Concrete, actionable findings from a full read-through of the firmware, web UI, and build config. This is a planning/backlog document only — nothing here has been implemented. Items already known and explicitly deferred this session (altitude hold, true loiter circles, setup-mode diagnostics/test-outputs screens, differential-thrust mixing, SD card logging) are intentionally left out.

## Safety / failsafes

- **GPS "valid" flag still never gets cleared once a fix is lost (now mitigated).** `gps_task()`'s real-hardware loop (`main/gps.c:346`) only writes `latest_gps_data` `if (gps.valid)`, so a `$GPRMC` with status `V` is dropped and `latest_gps_data.valid` stays `true` at the last good fix. This is no longer dangerous: `gps_data_t` now carries `timestamp_us`, and every nav consumer (`get_fresh_fix()`/`get_current_heading_deg()` in `main/nav.c`) treats a fix older than `GPS_FIX_MAX_AGE_US` (2s) as no fix. Remaining cleanup: write `latest_gps_data.valid = false` on a status-`V` sentence so the flag means what it says, instead of relying on the age check alone.
- **No staleness/age tracking on IMU data.** GPS now has it (see above), but `imu_data_t` (`main/include/imu.h:92`) still has no timestamp: a run of failed `icm_read()` calls in `imu_task()` just logs "failed to read IMU" and leaves `imu_data` frozen, and `read_attitude()` (`main/main.c:702`) has no age check. Recommend a `last_update_us` field (mirroring `rc_input_t` and `gps_data_t`) and a max-age check in `read_attitude()` that forces the safe fallback once the attitude goes stale, not just when the IMU is outright absent.
- **RC signal-loss failsafe only watches one channel.** `get_rc_mode_status()` (`main/main.c:364`), which `control_task()` uses for signal loss, only tests `RC_SWITCH`'s own `last_update_us` via `is_stale()`, and `log_rc_gaps()` (`main/main.c:936`) only logs gaps on that same channel. If a different channel (aileron, elevator, throttle) loses its individual wire/signal while the switch channel keeps updating fine, staleness goes undetected and the frozen last-received value for that one channel gets passed straight through in manual mode. Consider checking staleness across all 6 RC channels, not just the mode switch.
- **RC capture's `last_update_us` updates even on a rejected pulse.** `rc_capture_cb()` (`main/rc_capture.c:31`) unconditionally refreshes `last_update_us` on every edge, even when the computed `width_us` fails the 800-2200us sanity check and gets discarded (`main/rc_capture.c:26-28`). A channel producing corrupted/glitchy edge timing (not a clean loss of signal) would never trip `is_stale()` even though `pulse_width_us` itself has been frozen at its last good value the whole time. Only refresh `last_update_us` when a pulse is actually accepted.
- **A transient IMU mutex timeout permanently disables autonomous mode for the rest of the boot.** `update_autonomous_outputs()` returns `false` both when `imu_ready` is false (a real, permanent driver failure — correct to latch) and when `xSemaphoreTake(imu_data_mutex, ...)` simply times out once (`read_attitude()`, `main/main.c:702-717`, `IMU_MUTEX_WAIT` = 15ms) — a transient contention blip, not a hardware fault. `control_task()` treats both identically and sets `critical_fault_latched = true` forever (`main/main.c:1083`), requiring a full power cycle to recover — which isn't possible mid-flight. Consider only latching on a sustained run of mutex-take failures (e.g. N consecutive), not a single miss.
- **Gyro bias calibration's timeout fallback is a silent no-op.** `calibrate_gyro_bias()` falls back to `GYRO_BIAS_*_DPS_DEFAULT` if the board never settles within `GYRO_CAL_TIMEOUT_MS` (`main/imu.c:236-240`), but those defaults are all hardcoded `0.0f` (`main/include/imu.h:85-87`) despite the comment there saying "placeholder until bench-derived from a real calibration run's logged result." In practice this fallback path currently means "apply zero correction at all" instead of the intended safety-net value. Run a real calibration, capture the logged `gyro_bias_x/y/z` output, and hardcode those numbers.
- **No mission waypoint coordinate validation.** `api_mission_post()` (`main/http_server.c:435`) checks that `lat`/`lon` are JSON numbers but never checks they're in a plausible range (`-90..90`/`-180..180`). A typo'd or malformed waypoint would be accepted and silently drive `heading_to_target()`/`distance_to_target()` (`main/gps_math.c`) with nonsense input, producing an unpredictable commanded heading/roll rather than a rejected request.

## Flight control / PID

- **`MADGWICK_BETA` (1.0, `main/imu.c:27`) is a first-attempt bench guess, not systematically tuned** — the in-code comment already says as much ("retune from real bench behavior... rather than assuming this value is final"). Unlike ROLL/PITCH/HEADING_PID_CFG, there's no SITL coverage for this at all (`sitl/`'s simulators inject attitude noise directly, they don't model raw accel/gyro/mag fusion) — worth a small offline harness that logs raw IMU samples during a bench disturbance and replays them through `MadgwickAHRS.cpp` at different beta values, rather than tuning by feel in the air.
- **Compass axis remap and hard-iron offsets are unverified against the real board.** `read_mag()`'s axis remap comment (`main/imu.c:164-167`) explicitly flags it as "NOT verified against this specific board," and `MAG_HARD_IRON_OFFSET_*_UT` (`main/include/imu.h:74-76`) are fixed constants bench-derived once, with a note to redo them "if the board's position relative to nearby servos/motor/wiring changes." Since these feed directly into `nav.c`'s heading-hold source, a wrong remap or stale offset could silently produce a consistently-wrong compass heading. Worth a simple in-field verification step (compare `imu-yaw` in the setup-mode UI against a known bearing) before ever trusting compass-based nav in flight, and ideally a documented recalibration step once the IMU is actually mounted in the airframe.

## Networking & web UI

- **Setup-mode AP password is a real value ("`flightline123`") committed and unchanged, despite its own comment saying to change it.** (`main/include/setup_mode_config.h:8-11`) The API is also completely unauthenticated once on the AP — anyone who's ever had the WPA2 password (or a fully open network, if it's ever blanked) can hit every `/api/*` endpoint with no session/token. Low real-world risk given the AP only exists in a deliberately-entered ground mode, but worth actually rotating the password before flying anywhere with other RF-capable people nearby, and treating the SSID/password as something to change per deployment rather than leave at the repo default.
- **No "connection lost" indicator in the web UI.** Every poll function (`pollOutputs`/`pollAirspeed`/`pollImu`/`pollGps` in `main/web/app.js:297-848`) silently swallows a failed fetch and just waits for the next interval. If the AP link actually drops while looking at, say, the live IMU or output-pulse-width readouts (exactly the screens used most heavily for bench verification this session), the numbers just freeze with no visual cue that they're stale rather than live. A simple "last updated Ns ago" or a banner after N consecutive poll failures would make bench sessions less error-prone.

## Hardware / unused features

- **`init_auxiliary_gpio()` and `aux_set_level()` are fully dead code.** Neither is called from anywhere in the firmware (confirmed via grep, 2026-10-08 — the only other reference to either is a comment in `main.c`). The README explicitly describes the AUX pins as being for "accessory things like LEDs, a payload-release servo/relay, etc." — the driver exists but nothing initializes the pins as outputs or exposes them through the setup-mode API. If any near-term plan depends on AUX outputs (payload release, status LED, buzzer), it needs `init_auxiliary_gpio()` called from `app_main()`/`setup_mode_run()` and likely a settable `/api/aux` endpoint, not just the existing driver.

## Testing / validation gaps

- **`AIRSPEED_PID_CFG` has no SITL coverage at all** (confirmed via `sitl/README.md` — it only covers `ROLL_PID_CFG`/`PITCH_PID_CFG` via `sitl_sim.exe` and `HEADING_PID_CFG` via `nav_sim.exe`). The current `k_p=2` is a desk estimate from the sensor's own accuracy spec (see the in-code derivation, `main/main.c:149-180`), not validated against an actual thrust/drag/mass plant model the way the attitude gains were. A throttle/airspeed plant model (thrust curve vs. RPM/PWM, drag vs. speed, mass) added to `sitl/` would let this gain get the same kind of systematic sweep-and-validate treatment the others already got.

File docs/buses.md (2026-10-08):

# Hardware Reference

Everything a firmware developer needs to know about this board's (v3.1) hardware —
pinout, protocols, onboard parts, external connectors, power architecture —
without opening KiCad. Pulled directly from the schematic netlist
(`kicad-cli sch export netlist`, re-pulled 2026-10-08) and cross-checked
against manufacturer datasheets. If GPIO assignments ever change in a future
hardware revision, this file needs a re-pull; it will drift otherwise.

**Note:** this describes the v3.1 board in `kicad/flight-controller/`. The
firmware in `main/` currently targets the built v2.1 board (ESP32-S3-DevKitC
carrier, PWM receiver, ICM-20948 over I2C), so none of the GPIO assignments
below are in the code yet. See the "Firmware to-do for bring-up" section of
`kicad/flight-controller/design-review-fixed-wing-drone.md`.

## Board overview

Custom flight controller for a fixed-wing RC plane, built around an
ESP32-S3-WROOM-1-N16R2 (16MB flash, 2MB quad PSRAM). Onboard: primary IMU,
backup IMU, barometer, microSD logging. Potential (supported but may not always
be connected in a specific drone) external (cabled, not populated on
this PCB): GPS+compass, airspeed sensor, LIDAR, UWB radio link, a second ESP
board over UART, an IR beacon LED. The airspeed and gps+compass will always be
connected; the rest are considered optional upgrades for a drone. Drives up to
6 servos and 2 ESCs, and takes a standard RC receiver over SBUS (RX-only) or a
bidirectional link such as TBS Crossfire/ExpressLRS (CRSF, RX + telemetry TX).
Has a USB-C port for debug/programming.

## MCU: ESP32-S3-WROOM-1-N16R2

LCSC `C2913205`, Espressif, 16MB flash + 2MB **quad** PSRAM (both integrated
in the module package).

- **Do not substitute an R8/R16V (octal PSRAM) module.** On those variants
  GPIO35/36/37 are wired internally to the octal PSRAM. This board uses those
  three pins for the microSD bus, which only works with quad PSRAM. The
  N16R2 is also rated −40–85 °C, versus −40–65 °C for the N16R8. In
  `sdkconfig`, PSRAM must be set to 2MB quad, not octal.
- **GPIO19 / GPIO20 are the native USB D− / D+ pins.** They're fixed by
  silicon, not routed through the GPIO matrix, and can't be reassigned to
  another peripheral.
- **Strapping pins (GPIO0, GPIO3, GPIO45, GPIO46)** — all four are in use on
  this board:
  - `GPIO0` = `BOOT` button. This is the pin's intended purpose: it and
    GPIO46 together select boot mode at reset (GPIO0=1 → SPI Boot from
    flash, the default; GPIO0=0 with GPIO46=0 → Joint Download Boot, i.e.
    UART/USB flashing mode). GPIO0 defaults to an internal weak pull-up
    (reads 1) when nothing external drives it.
  - `GPIO46` = `STATUS_LED`, driven through a 220Ω resistor (`R5`) and LED
    (`D1`) to ground. GPIO46 defaults to an internal weak pull-down (reads 0)
    at reset. The LED string can't source current into the pin, so the strap
    still reads its correct default level during boot-mode sampling.
  - `GPIO45` = `LED_TOGGLE`, the IR beacon MOSFET gate (see "Other onboard
    parts"). GPIO45 is the VDD_SPI voltage strap when eFuse
    `EFUSE_VDD_SPI_FORCE` is not set: 0 → 3.3V, 1 → 1.8V. `R17` (100kΩ)
    pulls the gate, and therefore GPIO45, to ground, so it reads 0 at reset
    and selects 3.3V, which is the correct VDD_SPI for this module either way.
  - `GPIO3` selects JTAG signal source at boot (only if the
    `STRAP_JTAG_SEL` eFuse is set). It has **no internal pull resistor** and
    must not be left floating. It's wired here to `GPS_RX`, driven by the
    external GPS module's UART TX output (idle high), which satisfies that
    requirement.
- **The RC link is on UART0** (`RC_SBUS` on GPIO44/`RXD0`, `RC_TX` on
  GPIO43/`TXD0`). The ROM bootloader prints its boot log to UART0 by default,
  so on every boot that log is transmitted out of `RC_TX` toward the
  receiver. Suppress ROM UART0 printing (eFuse, or GPIO46's log-control
  strap), or move the console to USB-Serial-JTAG.

## Power architecture

```
Battery/UBEC ──> J20 "FC UBEC Input" (pin 2) ──> D5 (B5819W Schottky) ──┐
                                                                         ├──> FC_5V
USB-C VBUS (J13) ──> D4 (ESD) + C17 ─────────> D3 (B5819W, one-way) ────┘       │
                                                              ┌──────────────────┴─────────────────┐
                                                              ▼                                    ▼
                                                      U4 (XC6220B331PR-G)                 U6 (AP2112K-3.3)
                                                      5V → ESP_3V3                        5V → SENSOR_3V3
                                                      powers U1, microSD,                 powers both IMUs,
                                                      LEDs, IR beacon feed                barometer, I2C pull-ups

FC_5V ──> ferrites L1/L2/L3/L4 ──> external connectors J14 (GPS), J8 (LIDAR), J10 (UWB), J15 (airspeed)

ESC1 connector (J22) BEC, pin 2 ─────────> SERVO_5V ──> servo connectors (J1-J6), RC receiver (J7), C20 (22µF)
```

VBUS and the battery both feed `FC_5V` in parallel, each through its own
one-way Schottky. Either can power the flight-computer rail on its own (e.g.
bench-testing over USB with no battery connected), and neither can push
current back out through the other's path. `FC_5V` sits at roughly
4.5–4.7V after the diode drop.

- **Two independent 5V domains, deliberately isolated.** `FC_5V`
  (flight-computer power) and `SERVO_5V` (actuator power) are separate nets
  with their own copper pours, enforced by a custom DRC rule
  (`fixed-wing-drone.kicad_dru`, `FC_SERVO_5V_isolation`) requiring ≥2mm
  clearance between them, so servo/ESC current transients or brownouts
  can't couple into the flight computer's own supply. Don't assume these are
  the same rail.
- **Reverse polarity: protected by connector pinout and diodes, not FETs.**
  `J20` is GND / V+ / GND (pins 1 / 2 / 3), so a 3-pin plug works either way
  round, and D5 blocks reverse current. The SERVO_5V input (`J22` pin 2)
  has no reverse-polarity element. The earlier AO3407A P-FET stages (Q1/Q2)
  were removed in v3.1: Q1 was redundant with D5, and Q2's thermal margin
  was inadequate for six servos.
- **U4 (Torex XC6220B331PR-G, SOT-89-5)** regulates `FC_5V` → `ESP_3V3`.
  Input cap C18 (22µF/25V 0805), output caps C10 (22µF) + C19 (4.7µF) + C11
  (100nF). Its thermal tab is tied to GND and stitched to the ground plane.
- **U6 (Diodes Inc AP2112K-3.3, SOT-23-5)** regulates `FC_5V` →
  `SENSOR_3V3` for both IMUs, the barometer and the I2C pull-ups. It's a
  separate LDO from the MCU's supply, so a noisy or loaded sensor rail can't
  sag the processor's power.
- **The UWB header (`J10`) gets 5V, not 3.3V** (FC_5V through ferrite L3).
  The UWB board must carry its own 3.3V LDO for the DWM3000.
- **Only one ESC connector's BEC is actually used for power.** `J22`
  ("ESC1")'s pin 2 feeds `SERVO_5V`. `J19` ("ESC2") pin 2 is intentionally
  left unconnected: if you plug an ESC with its own BEC into J19, that BEC's
  output goes nowhere. Don't feed BEC power into both ESC connectors
  expecting redundancy.

## Protected external interfaces

All ESD protection is on the USB port and the RC receiver connector. Nothing
else has any:

- **USB-C VBUS** (`J13`): `D4` (ESD5Z5.0T1G) plus a 10µF cap (`C17`),
  ahead of the D3 blocking diode.
- **USB-C D+/D−**: `U5` (USBLC6-2SC6) ESD array.
- **RC receiver SBUS line** (`J7` pin 1, `RC_SBUS`): `D6` (ESD5Z5.0T1G)
  at the connector, then a 330Ω series resistor (`R27`) to the MCU.
- **RC receiver telemetry TX line** (`J7` pin 4, `RC_TX`): `D7`
  (ESD5Z5.0T1G) at the connector, then a 330Ω series resistor (`R26`).

Every other external connector (servo outputs, ESC signal lines, the I2C
sensor headers, GPS/compass, inter-ESP UART, UWB SPI header, IR beacon) has
no ESD protection beyond the MCU's own I/O pins.

## Sensor buses

**SPI — one shared sensor bus, five chip-selects.** `SCK` (GPIO14) /
`MOSI` (GPIO47) / `MISO` (GPIO21) are common to all of these:

| Device | CS net (GPIO) | Notes |
|---|---|---|
| Primary IMU (`U2`, ICM-42688-P) | `IMU1_CS` (GPIO18) | `INT1` wired to `IMU1_INT` (GPIO12). `INT2/FSYNC/CLKIN` (pin 9) and the reserved pins are unconnected. |
| Backup IMU (`U3`, BMI088) | `IMU2_ACCEL_CS` (GPIO15) + `IMU2_GYRO_CS` (GPIO7) | Two CS lines: the accelerometer and gyroscope are separate dies in one package. **All four interrupt pins (INT1–INT4) are unconnected.** Poll it. |
| Barometer (`U7`, DPS368) | `BAROMETER_CS` (GPIO17) | SPI mode 3 only. |
| UWB radio (external, via `J10`) | `UWB_CS` (GPIO16) | Interrupt on `UWB_INT` (GPIO13). Shares the bus over an off-board cable with no series resistors, so a harness fault on MISO takes out both IMUs and the barometer too. |

None of the five CS lines has an external pull-up. Drive them all high (with
internal pull-ups enabled) at the very start of `app_main`, before any SPI
init.

**SPI — dedicated microSD bus** on its own SPI host:

| Signal | GPIO |
|---|---|
| `SD_SCK` | 35 |
| `SD_MOSI` | 36 |
| `SD_CS` | 37 |
| `SD_MISO` | 8 |
| `SD_CARD_DETECT` | 4 (10kΩ pull-up `R11`) |

`SD_MISO`/`SD_CS`/`SD_MOSI` have 10kΩ pull-ups (`R28`/`R29`/`R30`) to
`ESP_3V3`. The unused DAT1/DAT2 card pins are pulled up via `R2`/`R1`.

**I2C — one shared external bus.** `SDA` = GPIO10, `SCL` = GPIO11, 4.7kΩ
pull-ups (`R20`/`R21`) to `SENSOR_3V3`. Only external, cabled sensors are on
this bus; no onboard sensor uses I2C:

| Connector | Purpose | Pinout |
|---|---|---|
| `J8` | LIDAR | 1 5V / 2 SCL / 3 SDA / 4 GND |
| `J14` | GPS/Compass (also carries GPS UART, see below) | 1 SDA / 2 GND / 3 GPS_RX / 4 GPS_TX / 5 5V / 6 SCL |
| `J15` | Airspeed sensor | 1 5V / 2 SCL / 3 SDA / 4 GND |

All three connectors' 5V pins are filtered through a ferrite bead (L2, L1,
L4 respectively) in series from `FC_5V`. This shows up as a separate
auto-named net on the connector side of each bead in netlist output, which is
expected and doesn't mean anything is disconnected.

**UART:**

| Net | GPIO | Purpose |
|---|---|---|
| `GPS_RX` / `GPS_TX` | 3 / 9 | GPS module UART, via `J14`. Pinout matches the BN-880 with TX/RX already crossed, so a straight-through cable works. BN-880 default is 38400 baud. |
| `INTER_ESP_RX` / `INTER_ESP_TX` | 5 / 6 | Link to the mission board, via `J11` (1 GND / 2 TX / 3 RX) |
| `RC_SBUS` | 44 (silicon `RXD0`) | RC receiver input (SBUS, or the RX half of a CRSF/ExpressLRS link), via `J7`. SBUS needs UART RX inversion enabled. |
| `RC_TX` | 43 (silicon `TXD0`) | RC receiver telemetry output (unused for plain SBUS; the TX half of a CRSF/ExpressLRS link), via `J7`. See the ROM boot-log note above. |

`J7` is a 4-pin connector: pin 1 `RC_SBUS` (signal in), pin 2 `SERVO_5V`,
pin 3 `GND`, pin 4 `RC_TX` (signal out).

## PWM outputs

6 servo channels + 2 ESC channels, each through its own 330Ω series resistor
before reaching its connector:

| Signal | GPIO | Connector |
|---|---|---|
| `SERVO_OUT_1` | 42 | `J1` |
| `SERVO_OUT_2` | 41 | `J2` |
| `SERVO_OUT_3` | 39 | `J3` |
| `SERVO_OUT_4` | 48 | `J4` |
| `SERVO_OUT_5` | 40 | `J5` |
| `SERVO_OUT_6` | 38 | `J6` |
| `ESC_OUT1` | 2 | `J22` ("ESC1", also the SERVO_5V power source, see above) |
| `ESC_OUT2` | 1 | `J19` ("ESC2", pin 2 NC) |

Servo connectors are signal / SERVO_5V / GND (pins 1 / 2 / 3). ESC_OUT1/2
have no pull-downs, so they float during boot until firmware drives them.
ESCs need a valid pulse train to arm, so this is low risk.

## USB-C debug port (`J13`)

16-pin GCT USB4105-GF-A receptacle, USB 2.0 only (no SuperSpeed pins).
`CC1`/`CC2` each have a 5.1kΩ pull-down (`R3`/`R4`) to GND: correct UFP
(sink) termination, so a compliant USB-C source will present VBUS. Native
USB D+/D− go to the MCU's GPIO20/GPIO19 through the `U5` USBLC6-2SC6 ESD
array, with no series resistors.

## Other onboard parts

- **`D1`** — status LED on GPIO46 via `R5` (220Ω). **`D2`** — power LED
  on `ESP_3V3` via `R6` (220Ω).
- **IR beacon output (`J9`)** — a 3-pin connector for an external IR LED.
  Pins 1 and 3 are fed from `ESP_3V3` through 33Ω current-limit resistors
  (`R24`/`R25`, 1206, 0.75W). Pin 2 is the low-side switch: `Q3` (AO3400A
  N-MOSFET), gate driven from GPIO45 (`LED_TOGGLE`) through `R16` (220Ω),
  with `R17` (100kΩ) pulling it off at boot.
- **`SW1`** — reset button. Pulls `EN` (chip enable/reset) to GND when
  pressed. `EN` has a 10kΩ pull-up to `ESP_3V3` (`R7`) and an RC filter
  (`C12` 1µF + `C14` 100nF) placed within a few mm of the module pin.
- **`SW2`** — BOOT button. Pulls GPIO0 to GND through a 100Ω series
  resistor (`R9`) when pressed. Hold it while tapping reset to enter
  UART/USB download mode (see the GPIO0/GPIO46 boot-mode note above).
- **Test points** — `TP1`–`TP3` (MOSI/MISO/SCK), `TP5`/`TP6` (SDA/SCL),
  `TP7` (ESP_3V3), `TP8` (SENSOR_3V3), `TP9` (FC_5V), `TP4`/`TP10` (GND).

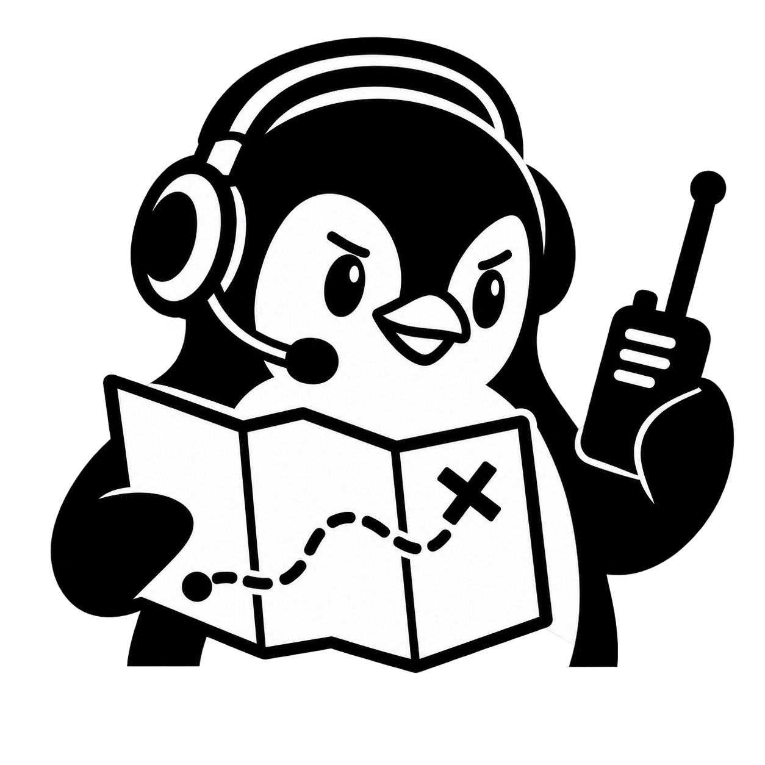
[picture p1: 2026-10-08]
artwork/mission-commander-penguin-transparent.png

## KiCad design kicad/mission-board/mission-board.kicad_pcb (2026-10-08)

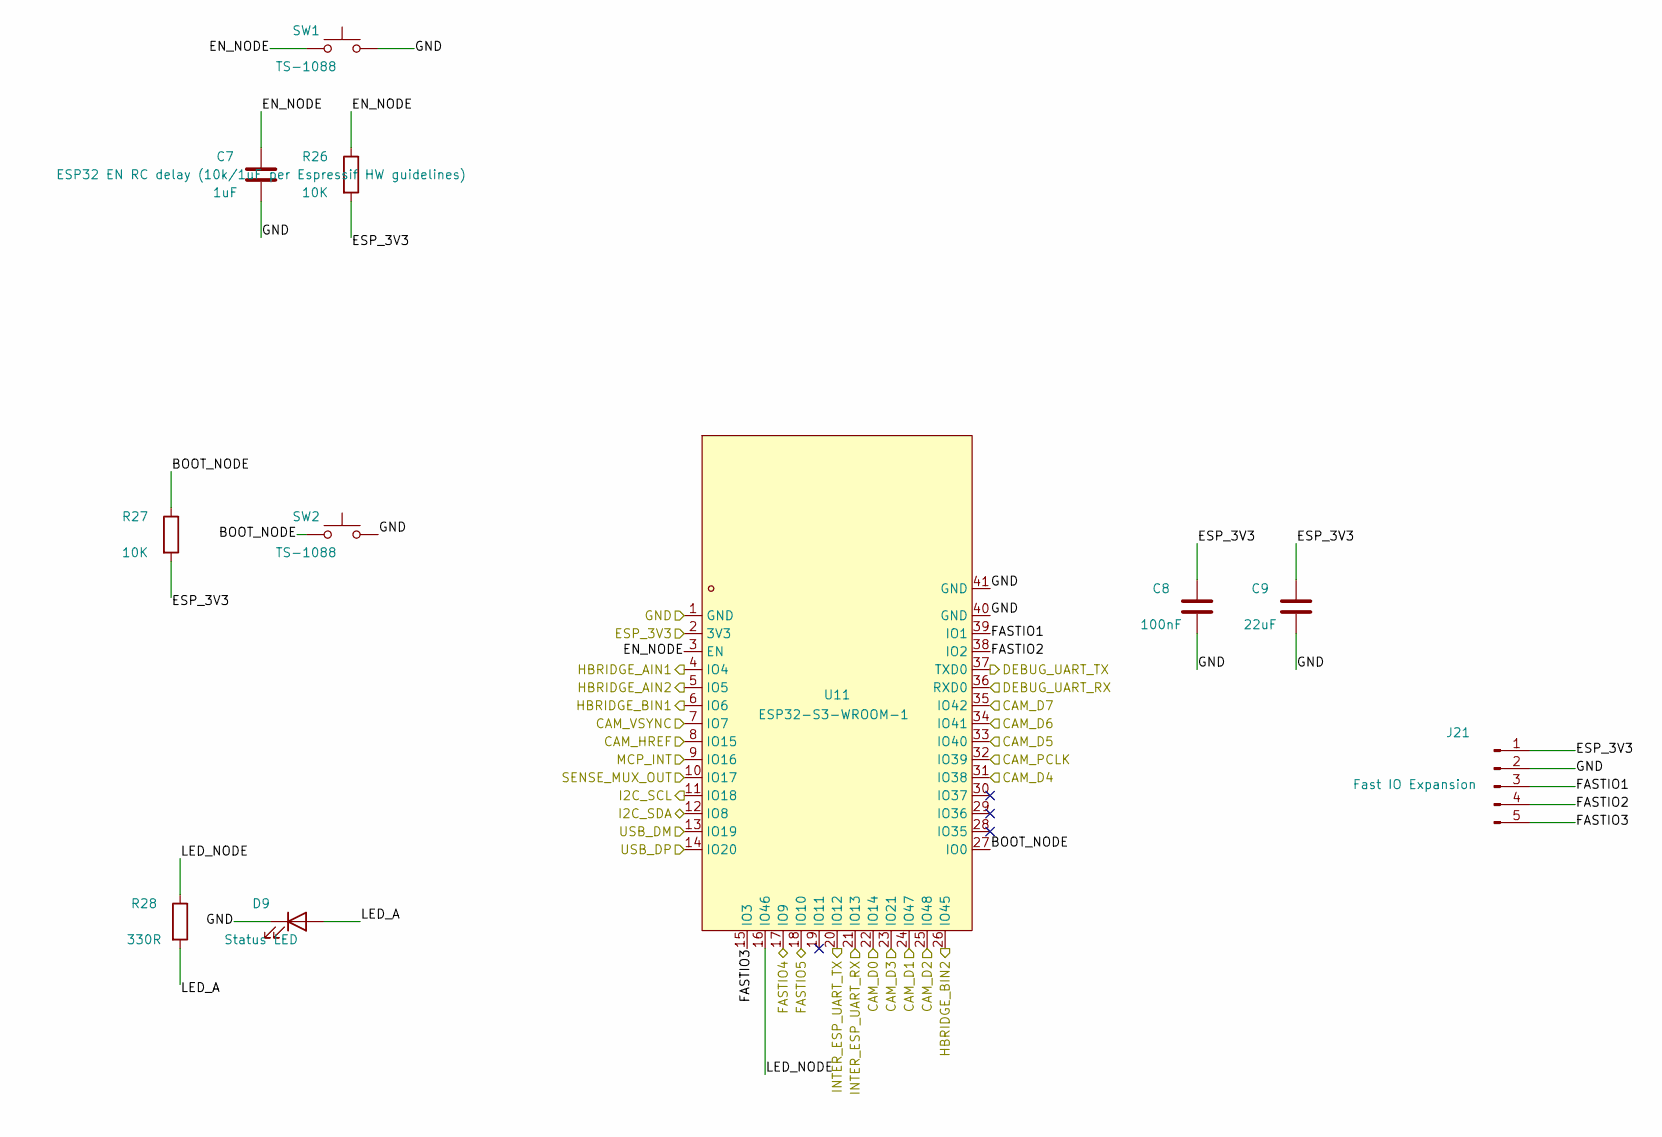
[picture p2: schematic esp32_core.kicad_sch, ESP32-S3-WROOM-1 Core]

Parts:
C7: 1uF; C_0402_1005Metric; LCSC Part C52923
C8: 100nF; C_0402_1005Metric; LCSC Part C1525
C9: 22uF; C_0805_2012Metric; LCSC Part C45783
D9: Status LED; LED_0603_1608Metric; LCSC Part C2286
J21: Fast IO Expansion; PinHeader_1x05_P2.54mm_Vertical; LCSC Part C2895846
R26, R27: 10K; R_0402_1005Metric; LCSC Part C25744
R28: 330R; R_0402_1005Metric; LCSC Part C25104
SW1, SW2: TS-1088; SW_SPST_TS-1088-xR020; LCSC Part C720477
U11: ESP32-S3-WROOM-1; WIRELM-SMD_ESP32-S3-WROOM-1; LCSC Part C2913202

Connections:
/CAM_D0: U11.22 (IO14); also elsewhere on the board
/CAM_D1: U11.24 (IO47); also elsewhere on the board
/CAM_D2: U11.25 (IO48); also elsewhere on the board
/CAM_D3: U11.23 (IO21); also elsewhere on the board
/CAM_D4: U11.31 (IO38); also elsewhere on the board
/CAM_D5: U11.33 (IO40); also elsewhere on the board
/CAM_D6: U11.34 (IO41); also elsewhere on the board
/CAM_D7: U11.35 (IO42); also elsewhere on the board
/CAM_HREF: U11.8 (IO15); also elsewhere on the board
/CAM_PCLK: U11.32 (IO39); also elsewhere on the board
/CAM_VSYNC: U11.7 (IO7); also elsewhere on the board
/DEBUG_UART_RX: U11.36 (RXD0); also elsewhere on the board
/DEBUG_UART_TX: U11.37 (TXD0); also elsewhere on the board
/ESP_3V3: C8.1, C9.1, J21.1, R26.2, R27.2, U11.2 (3V3); also elsewhere on the board
/FASTIO4: U11.17 (IO9); also elsewhere on the board
/FASTIO5: U11.18 (IO10); also elsewhere on the board
/GND: C7.2, C8.2, C9.2, D9.1 (K), J21.2, SW1.2, SW2.2, U11.1 (GND), U11.40 (GND), U11.41 (GND); also elsewhere on the board
/HBRIDGE_AIN1: U11.4 (IO4); also elsewhere on the board
/HBRIDGE_AIN2: U11.5 (IO5); also elsewhere on the board
/HBRIDGE_BIN1: U11.6 (IO6); also elsewhere on the board
/HBRIDGE_BIN2: U11.26 (IO45); also elsewhere on the board
/I2C_SCL: U11.11 (IO18); also elsewhere on the board
/I2C_SDA: U11.12 (IO8); also elsewhere on the board
/INTER_ESP_UART_RX: U11.21 (IO13); also elsewhere on the board
/INTER_ESP_UART_TX: U11.20 (IO12); also elsewhere on the board
/MCP_INT: U11.9 (IO16); also elsewhere on the board
/SENSE_MUX_OUT: U11.10 (IO17); also elsewhere on the board
/USB_DM: U11.13 (IO19); also elsewhere on the board
/USB_DP: U11.14 (IO20); also elsewhere on the board
/esp32_core/BOOT_NODE: R27.1, SW2.1, U11.27 (IO0)
/esp32_core/EN_NODE: C7.1, R26.1, SW1.1, U11.3 (EN)
/esp32_core/FASTIO1: J21.3, U11.39 (IO1)
/esp32_core/FASTIO2: J21.4, U11.38 (IO2)
/esp32_core/FASTIO3: J21.5, U11.15 (IO3)
/esp32_core/LED_A: D9.2 (A), R28.2
/esp32_core/LED_NODE: R28.1, U11.16 (IO46)

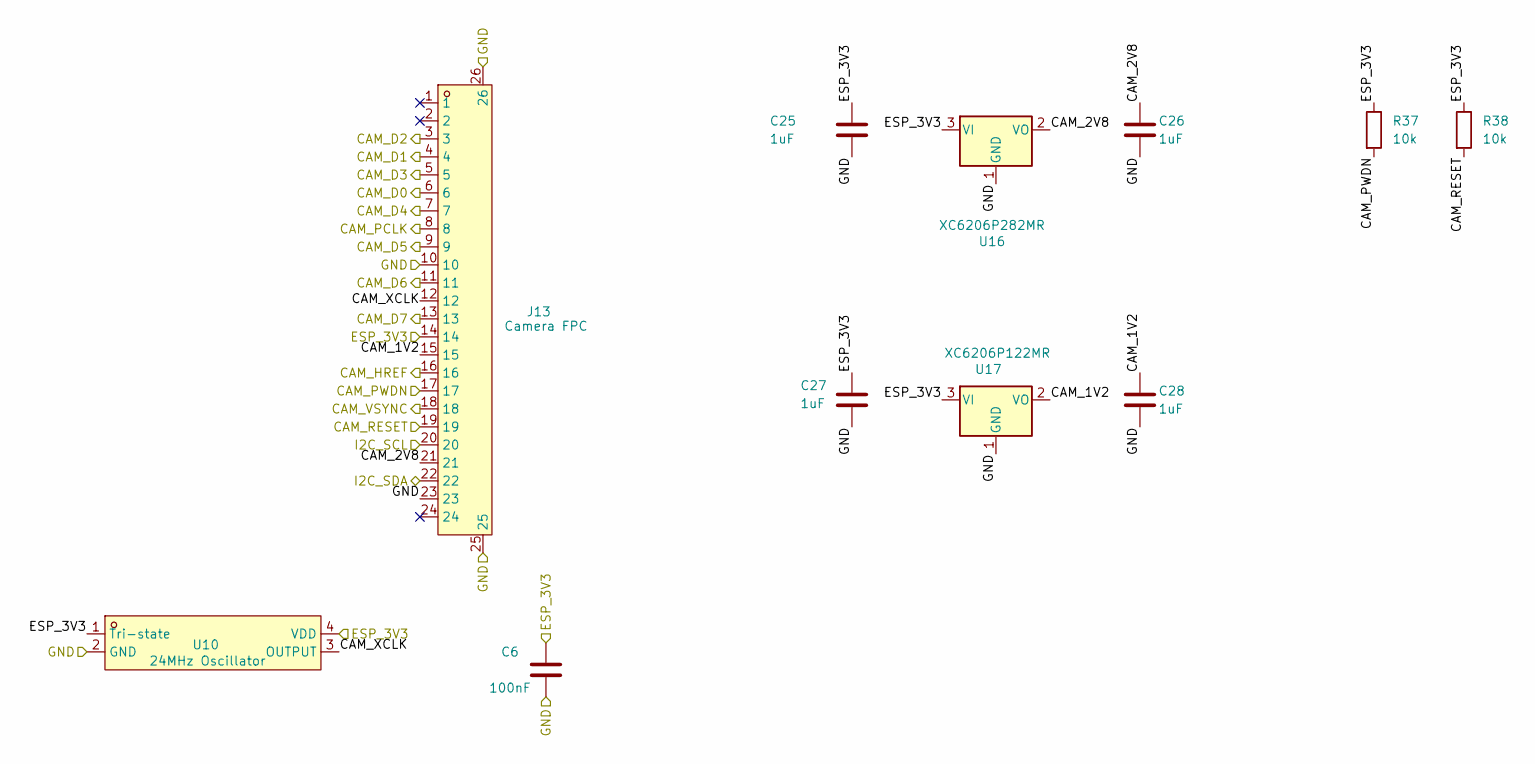
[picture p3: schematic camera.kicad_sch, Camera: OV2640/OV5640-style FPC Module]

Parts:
C6: 100nF; C_0402_1005Metric; LCSC Part C1525
C25, C26, C27, C28: 1uF; C_0402_1005Metric; LCSC Part C52923
J13: Camera FPC; FPC-SMD_24P-P0.50_FPC-05F-24PH20; LCSC Part C2856805
R37, R38: 10k; R_0402_1005Metric; LCSC Part C25744
U10: 24MHz Oscillator; OSC-SMD_4P-L3.2-W2.5-BL-1; LCSC Part C717686
U16: XC6206P282MR; SOT-23-3; MPN XC6206P282MR; LCSC Part C5148690
U17: XC6206P122MR; SOT-23-3; MPN XC6206P122MR-Y; LCSC Part C49446785

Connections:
/CAM_D0: J13.6; also elsewhere on the board
/CAM_D1: J13.4; also elsewhere on the board
/CAM_D2: J13.3; also elsewhere on the board
/CAM_D3: J13.5; also elsewhere on the board
/CAM_D4: J13.7; also elsewhere on the board
/CAM_D5: J13.9; also elsewhere on the board
/CAM_D6: J13.11; also elsewhere on the board
/CAM_D7: J13.13; also elsewhere on the board
/CAM_HREF: J13.16; also elsewhere on the board
/CAM_PCLK: J13.8; also elsewhere on the board
/CAM_PWDN: J13.17, R37.2; also elsewhere on the board
/CAM_RESET: J13.19, R38.2; also elsewhere on the board
/CAM_VSYNC: J13.18; also elsewhere on the board
/ESP_3V3: C6.1, C25.1, C27.1, J13.14, R37.1, R38.1, U10.1 (Tri-state), U10.4 (VDD), U16.3 (VI), U17.3 (VI); also elsewhere on the board
/GND: C6.2, C25.2, C26.2, C27.2, C28.2, J13.10, J13.23, J13.25, J13.26, U10.2 (GND), U16.1 (GND), U17.1 (GND); also elsewhere on the board
/I2C_SCL: J13.20; also elsewhere on the board
/I2C_SDA: J13.22; also elsewhere on the board
/camera/CAM_1V2: C28.1, J13.15, U17.2 (VO)
/camera/CAM_2V8: C26.1, J13.21, U16.2 (VO)
/camera/CAM_XCLK: J13.12, U10.3 (OUTPUT)

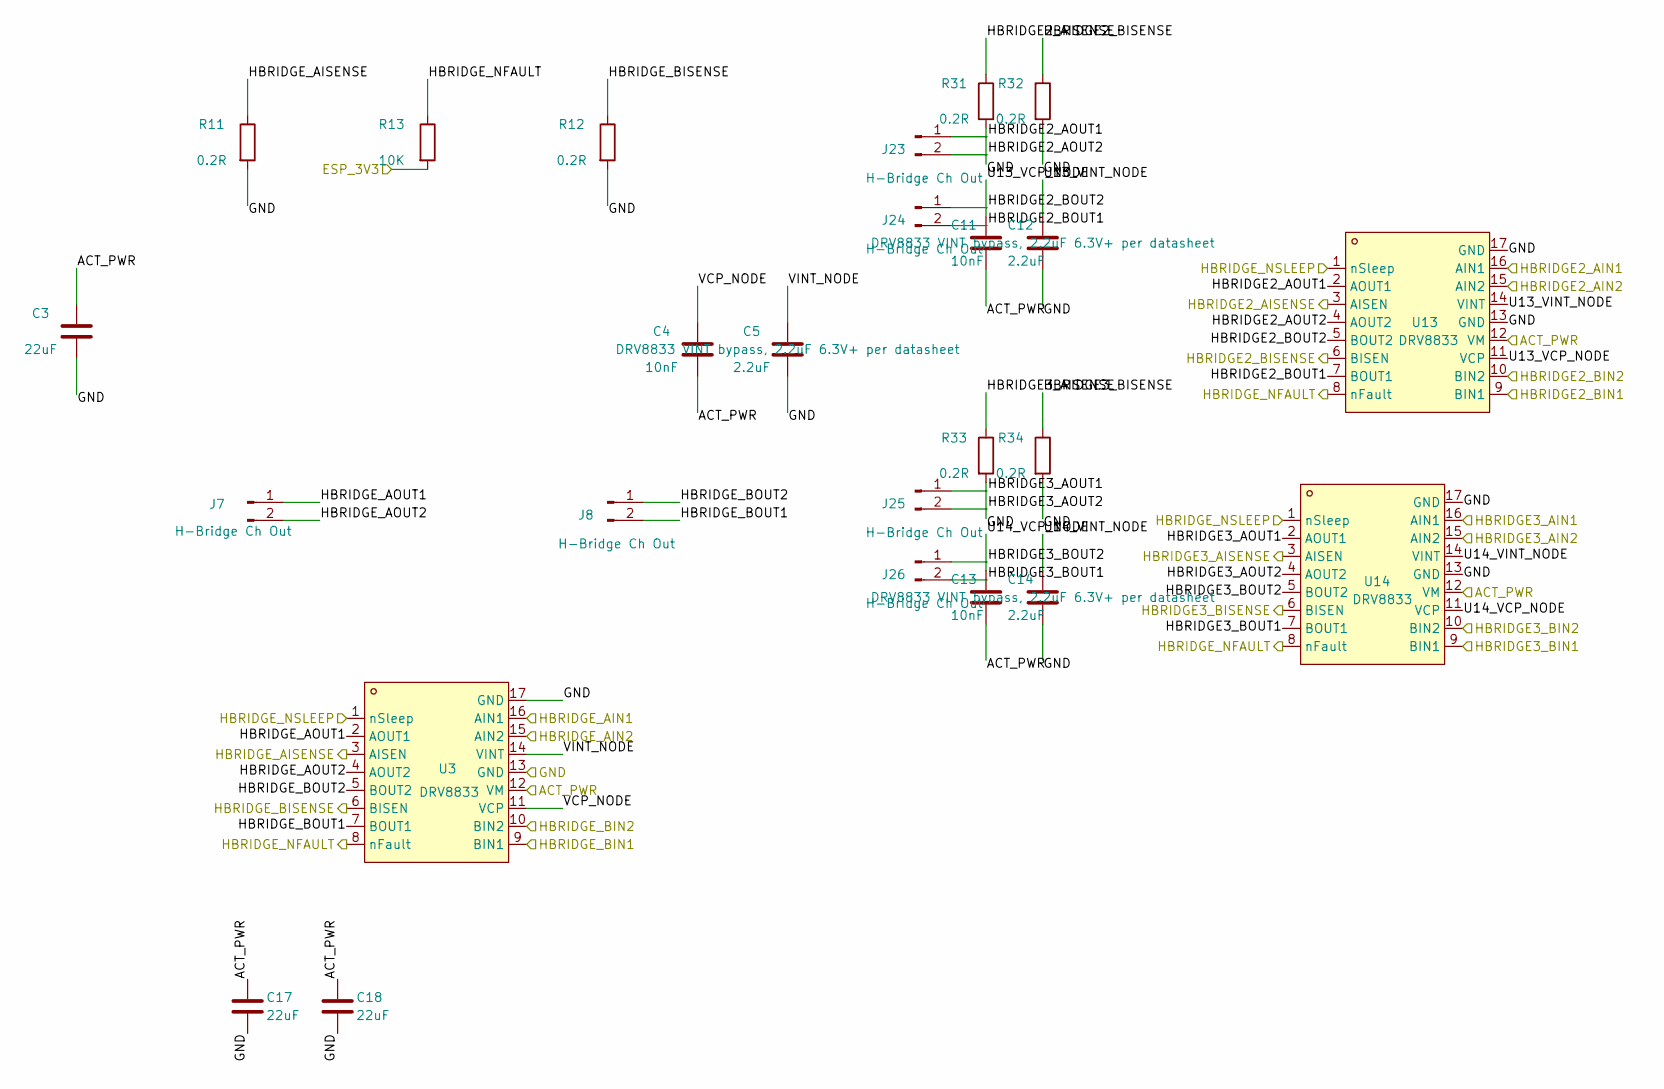
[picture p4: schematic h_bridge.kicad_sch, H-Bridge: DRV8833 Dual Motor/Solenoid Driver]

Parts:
C3, C17, C18: 22uF; C_0805_2012Metric; LCSC Part C45783
C4, C11, C13: 10nF; C_0402_1005Metric; LCSC Part C15195
C5, C12, C14: 2.2uF; C_0603_1608Metric; LCSC Part C23630
J7, J8, J23, J24, J25, J26: H-Bridge Ch Out; JST_XH_B2B-XH-A_1x02_P2.50mm_Vertical; LCSC Part C158012
R11, R12, R31, R32, R33, R34: 0.2R; R_1206_3216Metric; LCSC Part C25335
R13: 10K; R_0402_1005Metric; LCSC Part C25744
U3, U13, U14: DRV8833; TSSOP-16_L5.0-W4.4-P0.65-LS6.4-BL-EP; LCSC Part C50506

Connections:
/ACT_PWR: C3.1, C4.2, C11.2, C13.2, C17.1, C18.1, U3.12 (VM), U13.12 (VM), U14.12 (VM); also elsewhere on the board
/ESP_3V3: R13.2; also elsewhere on the board
/GND: C3.2, C5.2, C12.2, C14.2, C17.2, C18.2, R11.2, R12.2, R31.2, R32.2, R33.2, R34.2, U3.13 (GND), U3.17 (GND), U13.13 (GND), U13.17 (GND), U14.13 (GND), U14.17 (GND); also elsewhere on the board
/HBRIDGE2_AIN1: U13.16 (AIN1); also elsewhere on the board
/HBRIDGE2_AIN2: U13.15 (AIN2); also elsewhere on the board
/HBRIDGE2_AISENSE: R31.1, U13.3 (AISEN); also elsewhere on the board
/HBRIDGE2_BIN1: U13.9 (BIN1); also elsewhere on the board
/HBRIDGE2_BIN2: U13.10 (BIN2); also elsewhere on the board
/HBRIDGE2_BISENSE: R32.1, U13.6 (BISEN); also elsewhere on the board
/HBRIDGE3_AIN1: U14.16 (AIN1); also elsewhere on the board
/HBRIDGE3_AIN2: U14.15 (AIN2); also elsewhere on the board
/HBRIDGE3_AISENSE: R33.1, U14.3 (AISEN); also elsewhere on the board
/HBRIDGE3_BIN1: U14.9 (BIN1); also elsewhere on the board
/HBRIDGE3_BIN2: U14.10 (BIN2); also elsewhere on the board
/HBRIDGE3_BISENSE: R34.1, U14.6 (BISEN); also elsewhere on the board
/HBRIDGE_AIN1: U3.16 (AIN1); also elsewhere on the board
/HBRIDGE_AIN2: U3.15 (AIN2); also elsewhere on the board
/HBRIDGE_AISENSE: R11.1, U3.3 (AISEN); also elsewhere on the board
/HBRIDGE_BIN1: U3.9 (BIN1); also elsewhere on the board
/HBRIDGE_BIN2: U3.10 (BIN2); also elsewhere on the board
/HBRIDGE_BISENSE: R12.1, U3.6 (BISEN); also elsewhere on the board
/HBRIDGE_NFAULT: R13.1, U3.8 (nFault), U13.8 (nFault), U14.8 (nFault); also elsewhere on the board
/HBRIDGE_NSLEEP: U3.1 (nSleep), U13.1 (nSleep), U14.1 (nSleep); also elsewhere on the board
/h_bridge/HBRIDGE2_AOUT1: J23.1, U13.2 (AOUT1)
/h_bridge/HBRIDGE2_AOUT2: J23.2, U13.4 (AOUT2)
/h_bridge/HBRIDGE2_BOUT1: J24.2, U13.7 (BOUT1)
/h_bridge/HBRIDGE2_BOUT2: J24.1, U13.5 (BOUT2)
/h_bridge/HBRIDGE3_AOUT1: J25.1, U14.2 (AOUT1)
/h_bridge/HBRIDGE3_AOUT2: J25.2, U14.4 (AOUT2)
/h_bridge/HBRIDGE3_BOUT1: J26.2, U14.7 (BOUT1)
/h_bridge/HBRIDGE3_BOUT2: J26.1, U14.5 (BOUT2)
/h_bridge/HBRIDGE_AOUT1: J7.1, U3.2 (AOUT1)
/h_bridge/HBRIDGE_AOUT2: J7.2, U3.4 (AOUT2)
/h_bridge/HBRIDGE_BOUT1: J8.2, U3.7 (BOUT1)
/h_bridge/HBRIDGE_BOUT2: J8.1, U3.5 (BOUT2)
/h_bridge/U13_VCP_NODE: C11.1, U13.11 (VCP)
/h_bridge/U13_VINT_NODE: C12.1, U13.14 (VINT)
/h_bridge/U14_VCP_NODE: C13.1, U14.11 (VCP)
/h_bridge/U14_VINT_NODE: C14.1, U14.14 (VINT)
/h_bridge/VCP_NODE: C4.1, U3.11 (VCP)
/h_bridge/VINT_NODE: C5.1, U3.14 (VINT)

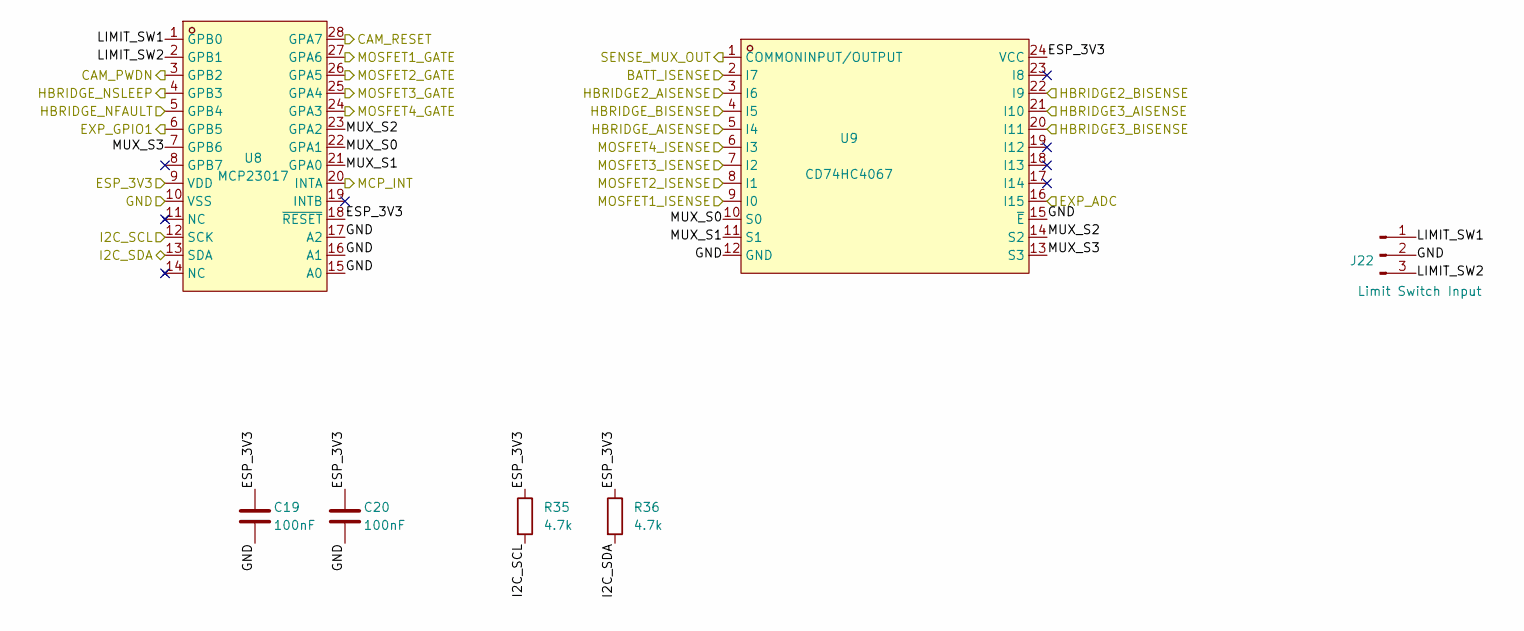
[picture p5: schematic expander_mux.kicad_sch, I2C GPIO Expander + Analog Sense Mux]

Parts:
C19, C20: 100nF; C_0402_1005Metric; LCSC Part C1525
J22: Limit Switch Input; JST_XH_B3B-XH-A_1x03_P2.50mm_Vertical; LCSC Part C144394
R35, R36: 4.7k; R_0402_1005Metric; LCSC Part C25900
U8: MCP23017; SOIC-28_L17.9-W7.5-P1.27-LS10.3-BL; LCSC Part C629440
U9: CD74HC4067; SOIC-24_L15.4-W7.5-P1.27-LS10.3-BL; LCSC Part C496123

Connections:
/BATT_ISENSE: U9.2 (I7); also elsewhere on the board
/CAM_PWDN: U8.3 (GPB2); also elsewhere on the board
/CAM_RESET: U8.28 (GPA7); also elsewhere on the board
/ESP_3V3: C19.1, C20.1, R35.1, R36.1, U8.9 (VDD), U8.18 (~RESET), U9.24 (VCC); also elsewhere on the board
/EXP_ADC: U9.16 (I15); also elsewhere on the board
/EXP_GPIO1: U8.6 (GPB5); also elsewhere on the board
/GND: C19.2, C20.2, J22.2, U8.10 (VSS), U8.15 (A0), U8.16 (A1), U8.17 (A2), U9.12 (GND), U9.15 (~E); also elsewhere on the board
/HBRIDGE2_AISENSE: U9.3 (I6); also elsewhere on the board
/HBRIDGE2_BISENSE: U9.22 (I9); also elsewhere on the board
/HBRIDGE3_AISENSE: U9.21 (I10); also elsewhere on the board
/HBRIDGE3_BISENSE: U9.20 (I11); also elsewhere on the board
/HBRIDGE_AISENSE: U9.5 (I4); also elsewhere on the board
/HBRIDGE_BISENSE: U9.4 (I5); also elsewhere on the board
/HBRIDGE_NFAULT: U8.5 (GPB4); also elsewhere on the board
/HBRIDGE_NSLEEP: U8.4 (GPB3); also elsewhere on the board
/I2C_SCL: R35.2, U8.12 (SCK); also elsewhere on the board
/I2C_SDA: R36.2, U8.13 (SDA); also elsewhere on the board
/MCP_INT: U8.20 (INTA); also elsewhere on the board
/MOSFET1_GATE: U8.27 (GPA6); also elsewhere on the board
/MOSFET1_ISENSE: U9.9 (I0); also elsewhere on the board
/MOSFET2_GATE: U8.26 (GPA5); also elsewhere on the board
/MOSFET2_ISENSE: U9.8 (I1); also elsewhere on the board
/MOSFET3_GATE: U8.25 (GPA4); also elsewhere on the board
/MOSFET3_ISENSE: U9.7 (I2); also elsewhere on the board
/MOSFET4_GATE: U8.24 (GPA3); also elsewhere on the board
/MOSFET4_ISENSE: U9.6 (I3); also elsewhere on the board
/SENSE_MUX_OUT: U9.1 (COMMONINPUT/OUTPUT); also elsewhere on the board
/expander_mux/LIMIT_SW1: J22.1, U8.1 (GPB0)
/expander_mux/LIMIT_SW2: J22.3, U8.2 (GPB1)
/expander_mux/MUX_S0: U8.22 (GPA1), U9.10 (S0)
/expander_mux/MUX_S1: U8.21 (GPA0), U9.11 (S1)
/expander_mux/MUX_S2: U8.23 (GPA2), U9.14 (S2)
/expander_mux/MUX_S3: U8.7 (GPB6), U9.13 (S3)

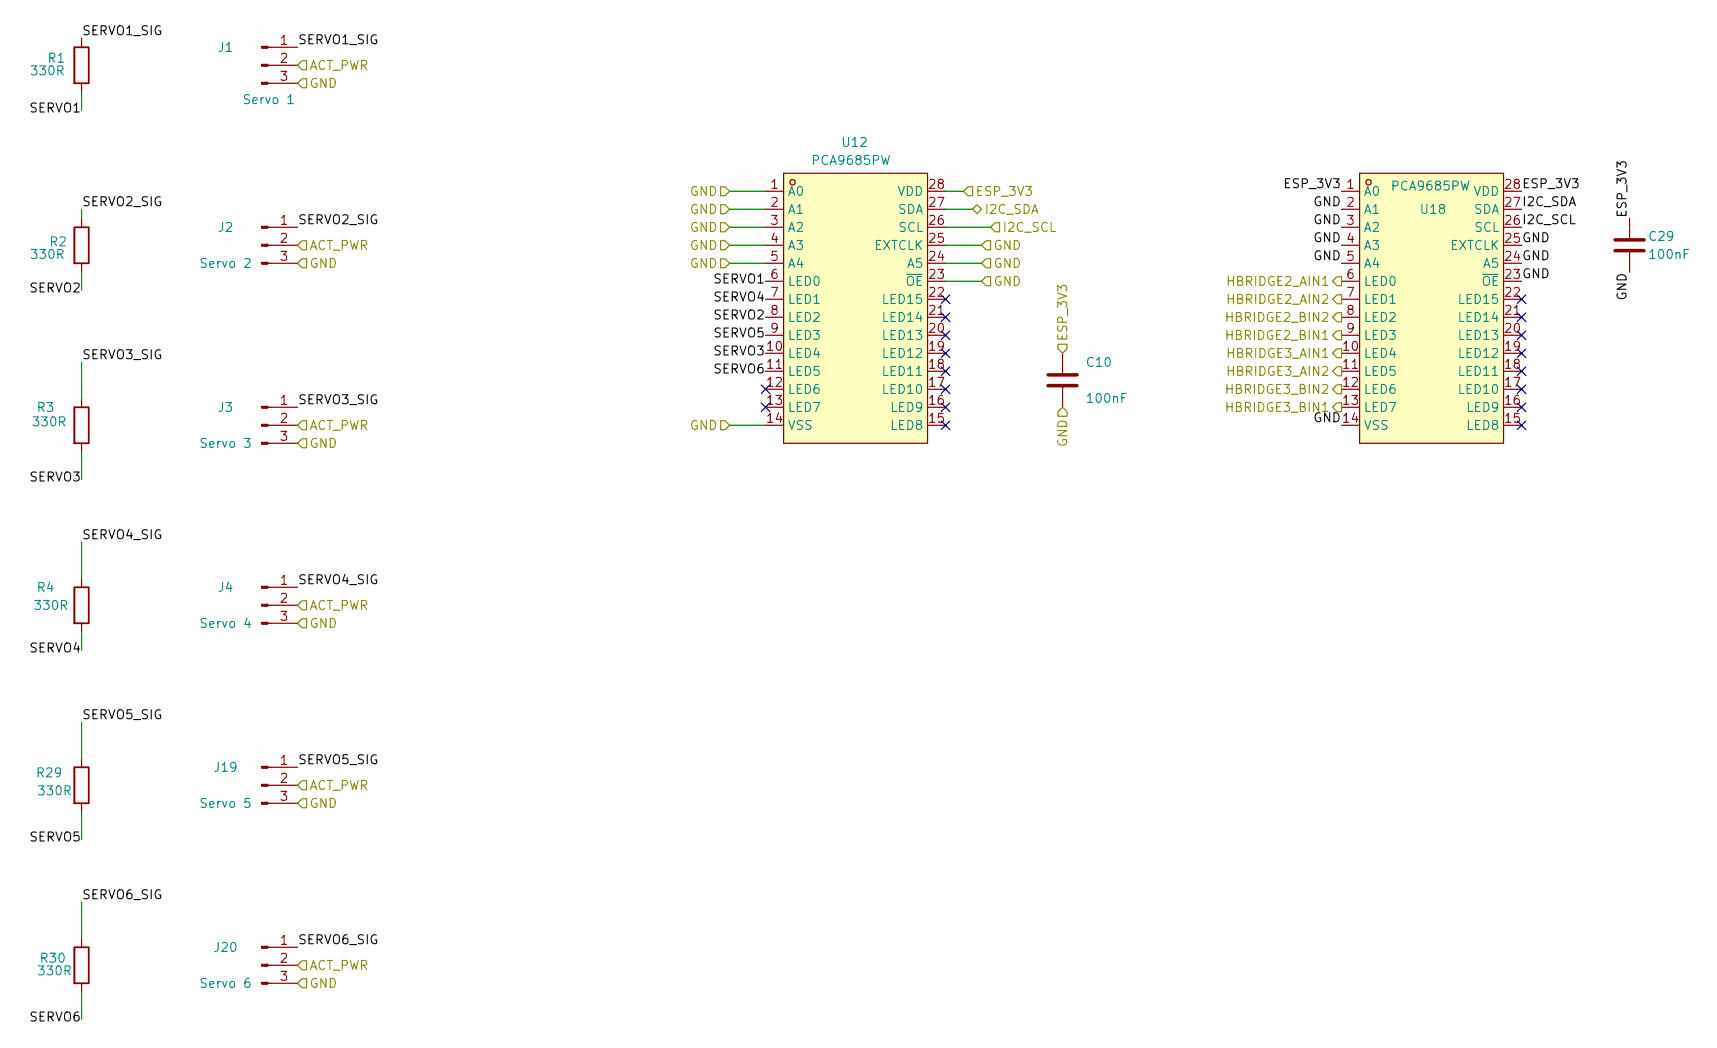
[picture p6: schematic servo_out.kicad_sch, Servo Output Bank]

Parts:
C10, C29: 100nF; C_0402_1005Metric; LCSC Part C1525
J1: Servo 1; Molex_KK-254_AE-6410-03A_1x03_P2.54mm_Vertical
J2: Servo 2; Molex_KK-254_AE-6410-03A_1x03_P2.54mm_Vertical
J3: Servo 3; Molex_KK-254_AE-6410-03A_1x03_P2.54mm_Vertical
J4: Servo 4; Molex_KK-254_AE-6410-03A_1x03_P2.54mm_Vertical
J19: Servo 5; Molex_KK-254_AE-6410-03A_1x03_P2.54mm_Vertical
J20: Servo 6; Molex_KK-254_AE-6410-03A_1x03_P2.54mm_Vertical
R1, R2, R3, R4, R29, R30: 330R; R_0402_1005Metric; LCSC Part C25104
U12, U18: PCA9685PW; TSSOP-28_L9.7-W4.4-P0.65-LS6.4-TL; LCSC Part C2678753

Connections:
/ACT_PWR: J1.2, J2.2, J3.2, J4.2, J19.2, J20.2; also elsewhere on the board
/ESP_3V3: C10.1, C29.1, U12.28 (VDD), U18.1 (A0), U18.28 (VDD); also elsewhere on the board
/GND: C10.2, C29.2, J1.3, J2.3, J3.3, J4.3, J19.3, J20.3, U12.1 (A0), U12.2 (A1), U12.3 (A2), U12.4 (A3), U12.5 (A4), U12.14 (VSS), U12.23 (~OE), U12.24 (A5), U12.25 (EXTCLK), U18.2 (A1), U18.3 (A2), U18.4 (A3), U18.5 (A4), U18.14 (VSS), U18.23 (~OE), U18.24 (A5), U18.25 (EXTCLK); also elsewhere on the board
/HBRIDGE2_AIN1: U18.6 (LED0); also elsewhere on the board
/HBRIDGE2_AIN2: U18.7 (LED1); also elsewhere on the board
/HBRIDGE2_BIN1: U18.9 (LED3); also elsewhere on the board
/HBRIDGE2_BIN2: U18.8 (LED2); also elsewhere on the board
/HBRIDGE3_AIN1: U18.10 (LED4); also elsewhere on the board
/HBRIDGE3_AIN2: U18.11 (LED5); also elsewhere on the board
/HBRIDGE3_BIN1: U18.13 (LED7); also elsewhere on the board
/HBRIDGE3_BIN2: U18.12 (LED6); also elsewhere on the board
/I2C_SCL: U12.26 (SCL), U18.26 (SCL); also elsewhere on the board
/I2C_SDA: U12.27 (SDA), U18.27 (SDA); also elsewhere on the board
/servo_out/SERVO1: R1.2, U12.6 (LED0)
/servo_out/SERVO1_SIG: J1.1, R1.1
/servo_out/SERVO2: R2.2, U12.8 (LED2)
/servo_out/SERVO2_SIG: J2.1, R2.1
/servo_out/SERVO3: R3.2, U12.10 (LED4)
/servo_out/SERVO3_SIG: J3.1, R3.1
/servo_out/SERVO4: R4.2, U12.7 (LED1)
/servo_out/SERVO4_SIG: J4.1, R4.1
/servo_out/SERVO5: R29.2, U12.9 (LED3)
/servo_out/SERVO5_SIG: J19.1, R29.1
/servo_out/SERVO6: R30.2, U12.11 (LED5)
/servo_out/SERVO6_SIG: J20.1, R30.1

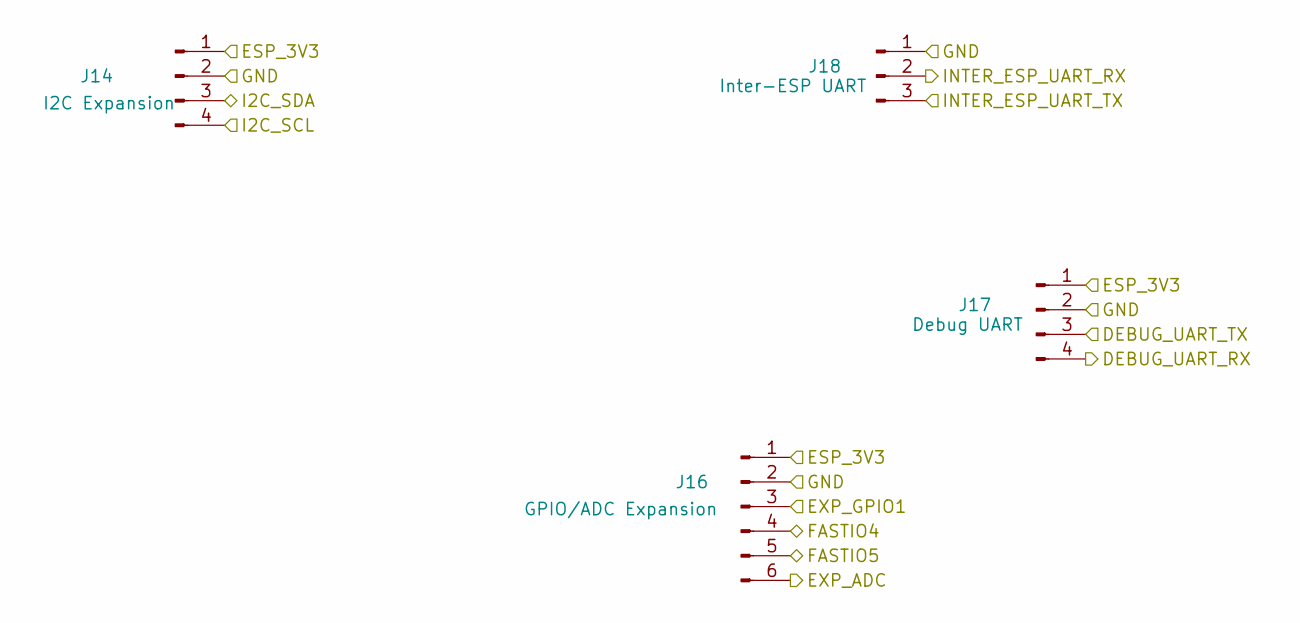
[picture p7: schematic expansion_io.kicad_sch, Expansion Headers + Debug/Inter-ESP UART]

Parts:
J14: I2C Expansion; PinHeader_1x04_P2.54mm_Vertical; LCSC Part C2895846
J16: GPIO/ADC Expansion; PinHeader_1x06_P2.54mm_Vertical; LCSC Part C2895846
J17: Debug UART; PinHeader_1x04_P2.54mm_Vertical; LCSC Part C2895846
J18: Inter-ESP UART; JST_GH_BM03B-GHS-TBT_1x03-1MP_P1.25mm_Vertical; LCSC Part C161691

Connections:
/DEBUG_UART_RX: J17.4; also elsewhere on the board
/DEBUG_UART_TX: J17.3; also elsewhere on the board
/ESP_3V3: J14.1, J16.1, J17.1; also elsewhere on the board
/EXP_ADC: J16.6; also elsewhere on the board
/EXP_GPIO1: J16.3; also elsewhere on the board
/FASTIO4: J16.4; also elsewhere on the board
/FASTIO5: J16.5; also elsewhere on the board
/GND: J14.2, J16.2, J17.2, J18.1; also elsewhere on the board
/I2C_SCL: J14.4; also elsewhere on the board
/I2C_SDA: J14.3; also elsewhere on the board
/INTER_ESP_UART_RX: J18.2; also elsewhere on the board
/INTER_ESP_UART_TX: J18.3; also elsewhere on the board

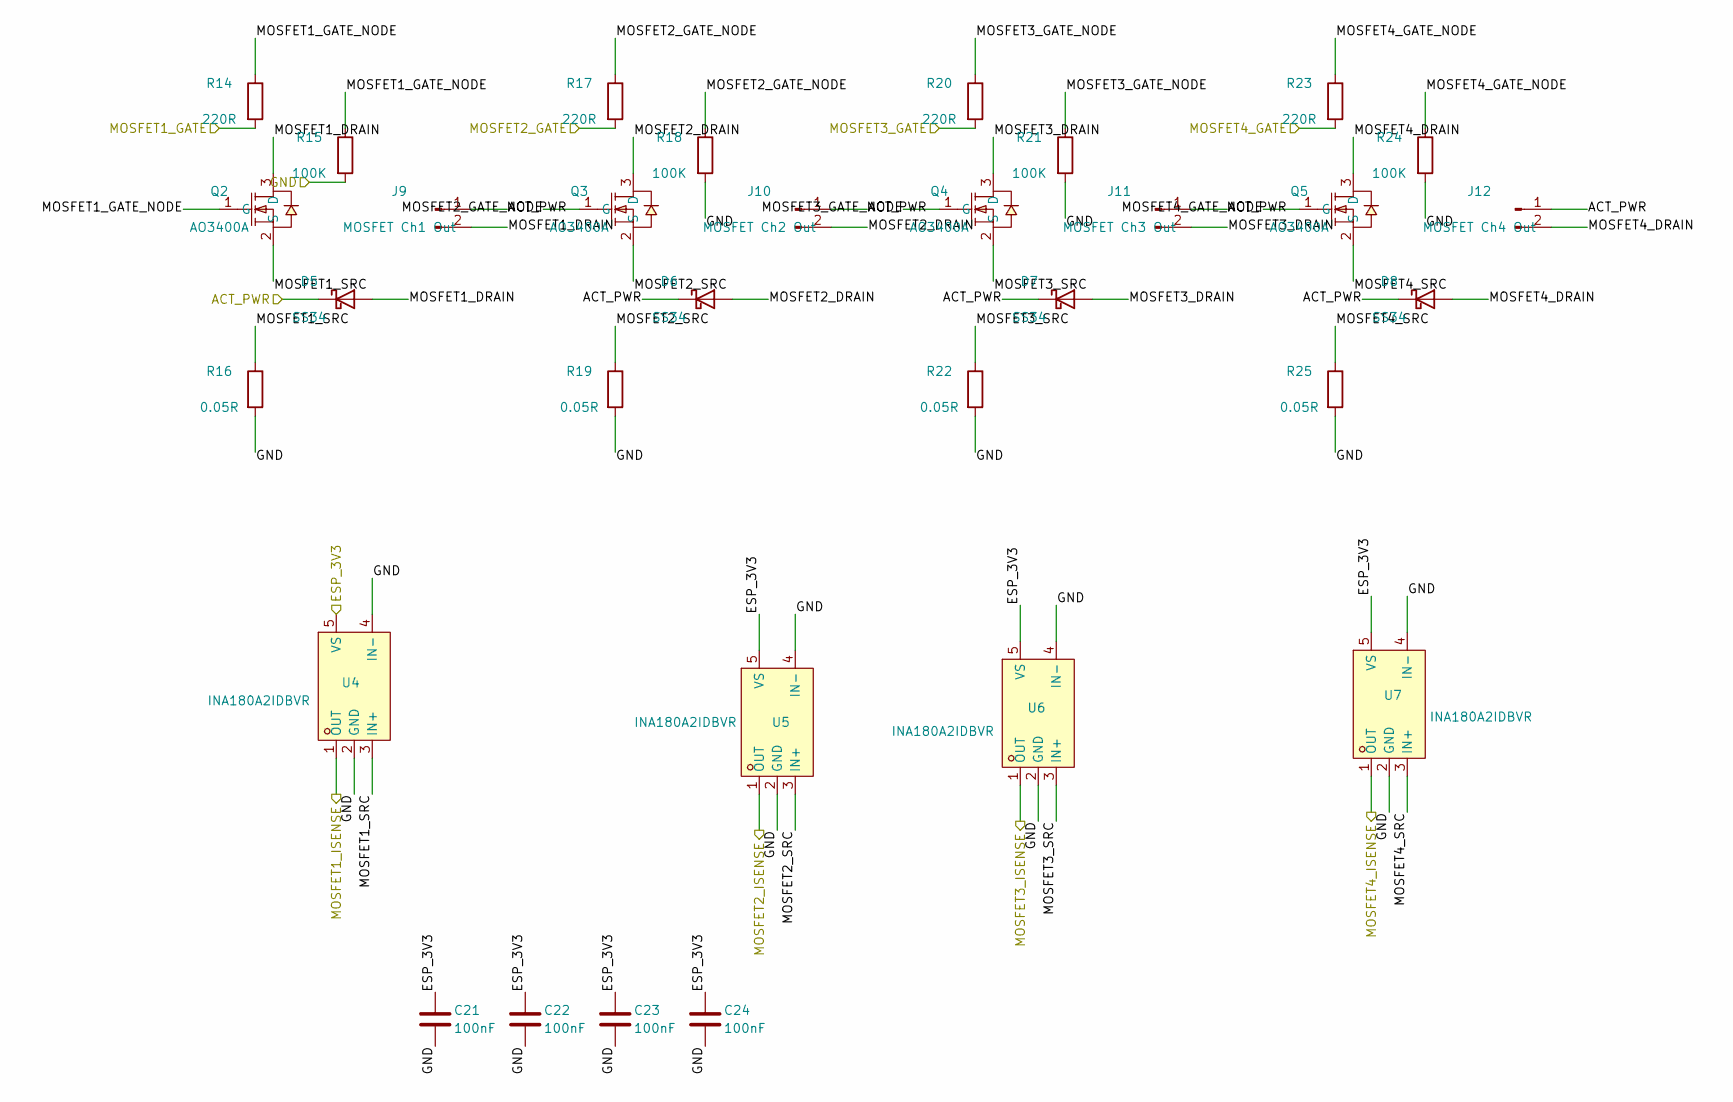
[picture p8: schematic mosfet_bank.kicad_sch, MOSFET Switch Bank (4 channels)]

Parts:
C21, C22, C23, C24: 100nF; C_0402_1005Metric; LCSC Part C1525
D5, D6, D7, D8: SS34; D_SMA; LCSC Part C8678
J9: MOSFET Ch1 Out; JST_XH_B2B-XH-A_1x02_P2.50mm_Vertical; LCSC Part C158012
J10: MOSFET Ch2 Out; JST_XH_B2B-XH-A_1x02_P2.50mm_Vertical; LCSC Part C158012
J11: MOSFET Ch3 Out; JST_XH_B2B-XH-A_1x02_P2.50mm_Vertical; LCSC Part C158012
J12: MOSFET Ch4 Out; JST_XH_B2B-XH-A_1x02_P2.50mm_Vertical; LCSC Part C158012
Q2, Q3, Q4, Q5: AO3400A; SOT-23-3_L2.9-W1.3-P1.90-LS2.4-BR; LCSC Part C20917
R14, R17, R20, R23: 220R; R_0402_1005Metric; LCSC Part C25091
R15, R18, R21, R24: 100K; R_0402_1005Metric; LCSC Part C25741
R16, R19, R22, R25: 0.05R; R_1206_3216Metric; LCSC Part C127691
U4, U5, U6, U7: INA180A2IDBVR; SOT-23-5_L3.0-W1.7-P0.95-LS2.8-BL; LCSC Part C192764

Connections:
/ACT_PWR: D5.1 (K), D6.1 (K), D7.1 (K), D8.1 (K), J9.1, J10.1, J11.1, J12.1; also elsewhere on the board
/ESP_3V3: C21.1, C22.1, C23.1, C24.1, U4.5 (VS), U5.5 (VS), U6.5 (VS), U7.5 (VS); also elsewhere on the board
/GND: C21.2, C22.2, C23.2, C24.2, R15.2, R16.2, R18.2, R19.2, R21.2, R22.2, R24.2, R25.2, U4.2 (GND), U4.4 (IN-), U5.2 (GND), U5.4 (IN-), U6.2 (GND), U6.4 (IN-), U7.2 (GND), U7.4 (IN-); also elsewhere on the board
/MOSFET1_GATE: R14.2; also elsewhere on the board
/MOSFET1_ISENSE: U4.1 (OUT); also elsewhere on the board
/MOSFET2_GATE: R17.2; also elsewhere on the board
/MOSFET2_ISENSE: U5.1 (OUT); also elsewhere on the board
/MOSFET3_GATE: R20.2; also elsewhere on the board
/MOSFET3_ISENSE: U6.1 (OUT); also elsewhere on the board
/MOSFET4_GATE: R23.2; also elsewhere on the board
/MOSFET4_ISENSE: U7.1 (OUT); also elsewhere on the board
/mosfet_bank/MOSFET1_DRAIN: D5.2 (A), J9.2, Q2.3 (D)
/mosfet_bank/MOSFET1_GATE_NODE: Q2.1 (G), R14.1, R15.1
/mosfet_bank/MOSFET1_SRC: Q2.2 (S), R16.1, U4.3 (IN+)
/mosfet_bank/MOSFET2_DRAIN: D6.2 (A), J10.2, Q3.3 (D)
/mosfet_bank/MOSFET2_GATE_NODE: Q3.1 (G), R17.1, R18.1
/mosfet_bank/MOSFET2_SRC: Q3.2 (S), R19.1, U5.3 (IN+)
/mosfet_bank/MOSFET3_DRAIN: D7.2 (A), J11.2, Q4.3 (D)
/mosfet_bank/MOSFET3_GATE_NODE: Q4.1 (G), R20.1, R21.1
/mosfet_bank/MOSFET3_SRC: Q4.2 (S), R22.1, U6.3 (IN+)
/mosfet_bank/MOSFET4_DRAIN: D8.2 (A), J12.2, Q5.3 (D)
/mosfet_bank/MOSFET4_GATE_NODE: Q5.1 (G), R23.1, R24.1
/mosfet_bank/MOSFET4_SRC: Q5.2 (S), R25.1, U7.3 (IN+)

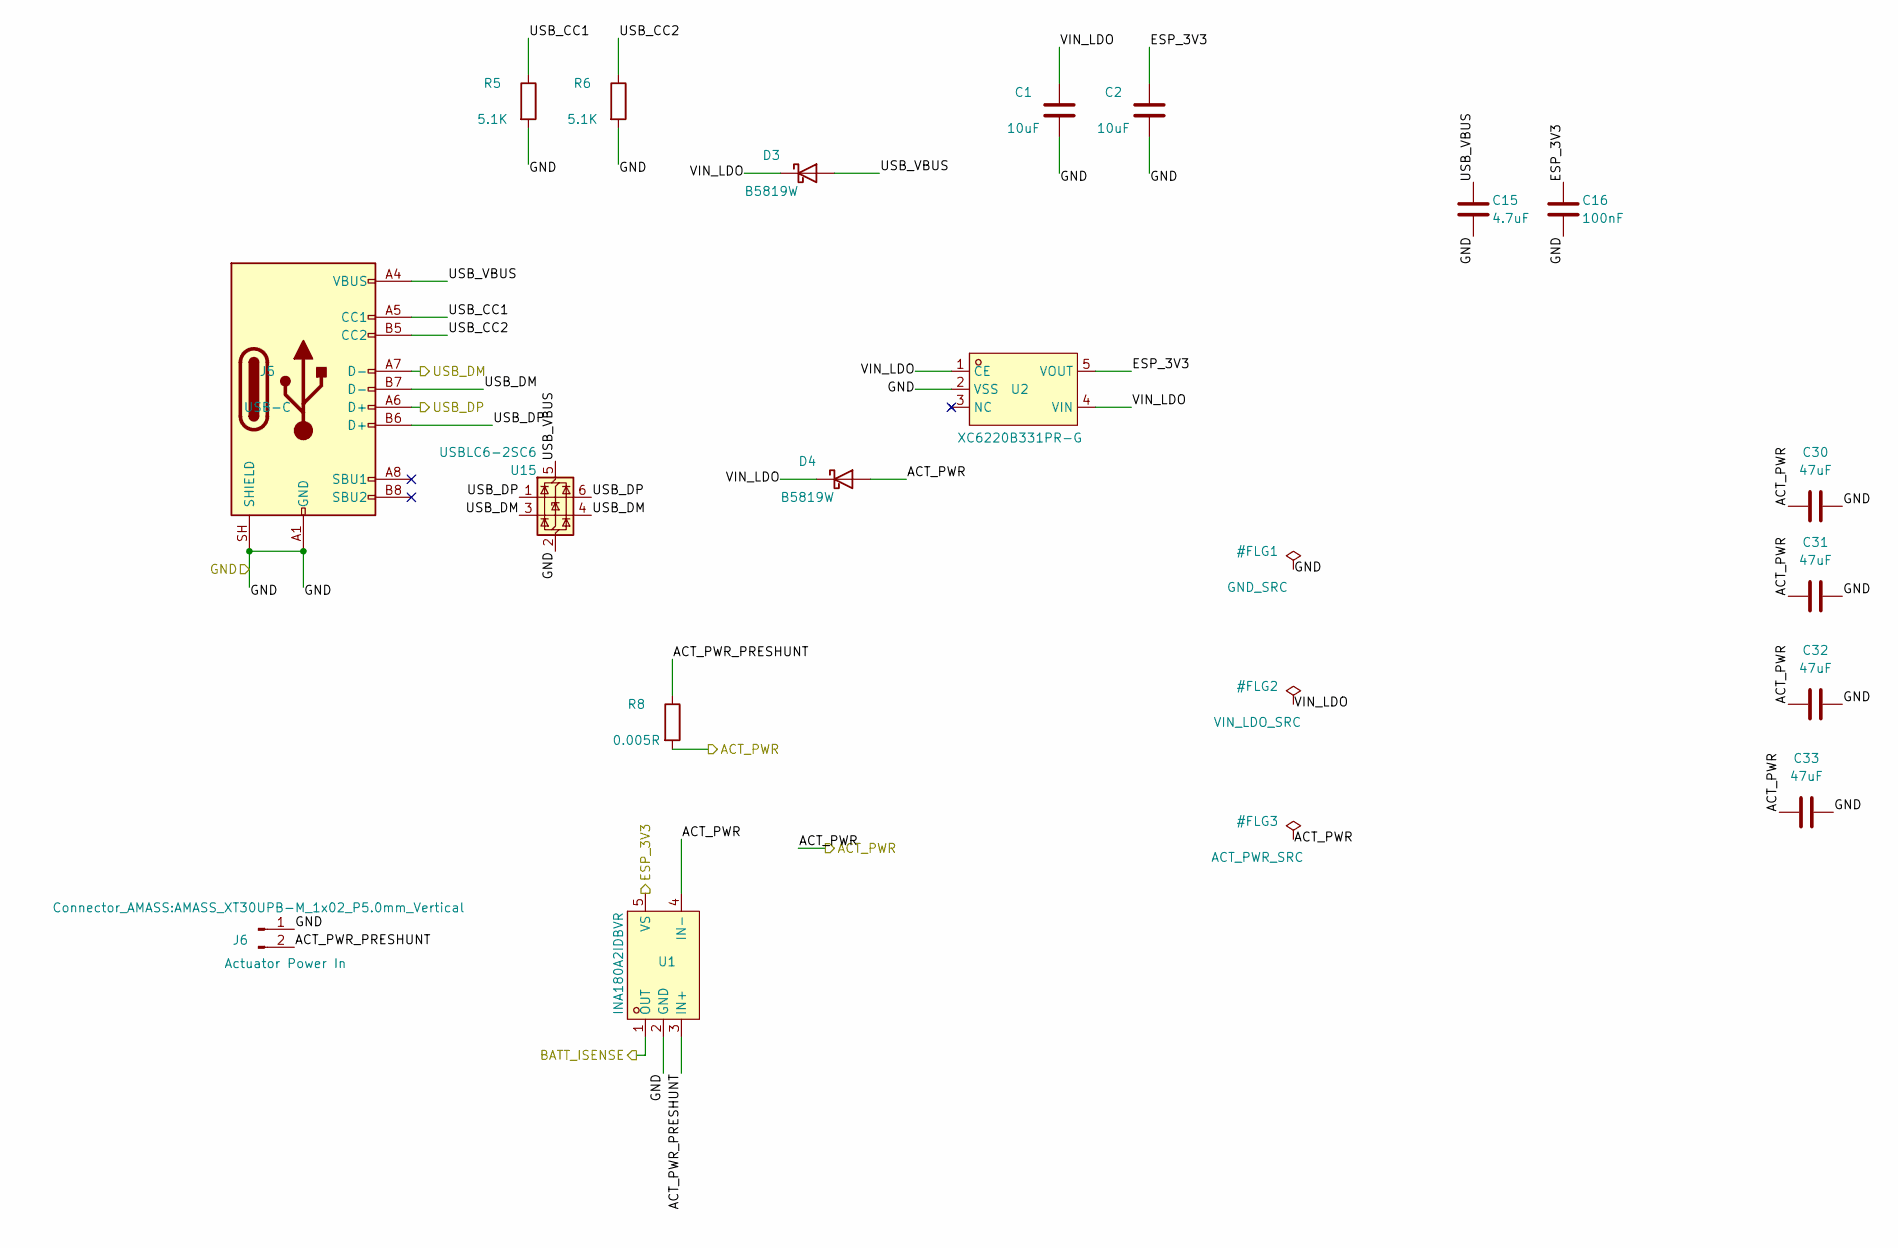
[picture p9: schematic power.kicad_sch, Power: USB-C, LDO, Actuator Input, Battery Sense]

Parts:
C1, C2: 10uF; C_0603_1608Metric; LCSC Part C19702
C15: 4.7uF; C_0603_1608Metric; LCSC Part C19666
C16: 100nF; C_0402_1005Metric; LCSC Part C1525
C30, C31, C32, C33: 47uF; C_1206_3216Metric; LCSC Part # C96123
D3, D4: B5819W; D_SOD-123; LCSC Part C8598
J5: USB-C; USB_C_Receptacle_GCT_USB4105-xx-A_16P_TopMnt_Horizontal; LCSC Part C3020560
J6: Actuator Power In; AMASS_XT30UPB-M_1x02_P5.0mm_Vertical; LCSC Part C428721
R5, R6: 5.1K; R_0402_1005Metric; LCSC Part C25905
R8: 0.005R; R_2512_6332Metric; LCSC Part C393074
U1: INA180A2IDBVR; SOT-23-5_L3.0-W1.7-P0.95-LS2.8-BL; LCSC Part C192764
U2: XC6220B331PR-G; SOT-89-5_L4.5-W2.5-P1.50-LS4.4-BR; LCSC Part C3013658
U15: USBLC6-2SC6; SOT-23-6; MPN USBLC6-2SC6; LCSC Part C7519

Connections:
/ACT_PWR: C30.1, C31.1, C32.1, C33.1, D4.2 (A), R8.2, U1.4 (IN-); also elsewhere on the board
/BATT_ISENSE: U1.1 (OUT); also elsewhere on the board
/ESP_3V3: C2.1, C16.1, U1.5 (VS), U2.5 (VOUT); also elsewhere on the board
/GND: C1.2, C2.2, C15.2, C16.2, C30.2, C31.2, C32.2, C33.2, J5.A1 (GND), J5.A12 (GND), J5.B1 (GND), J5.B12 (GND), J5.SH (SHIELD), J6.1, R5.2, R6.2, U1.2 (GND), U2.2 (VSS), U15.2 (GND); also elsewhere on the board
/USB_DM: J5.A7 (D-), J5.B7 (D-), U15.3 (I/O2), U15.4 (I/O2); also elsewhere on the board
/USB_DP: J5.A6 (D+), J5.B6 (D+), U15.1 (I/O1), U15.6 (I/O1); also elsewhere on the board
/power/ACT_PWR_PRESHUNT: J6.2, R8.1, U1.3 (IN+)
/power/USB_CC1: J5.A5 (CC1), R5.1
/power/USB_CC2: J5.B5 (CC2), R6.1
/power/USB_VBUS: C15.1, D3.2 (A), J5.A4 (VBUS), J5.A9 (VBUS), J5.B4 (VBUS), J5.B9 (VBUS), U15.5 (VBUS)
/power/VIN_LDO: C1.1, D3.1 (K), D4.1 (K), U2.1 (CE), U2.4 (VIN)

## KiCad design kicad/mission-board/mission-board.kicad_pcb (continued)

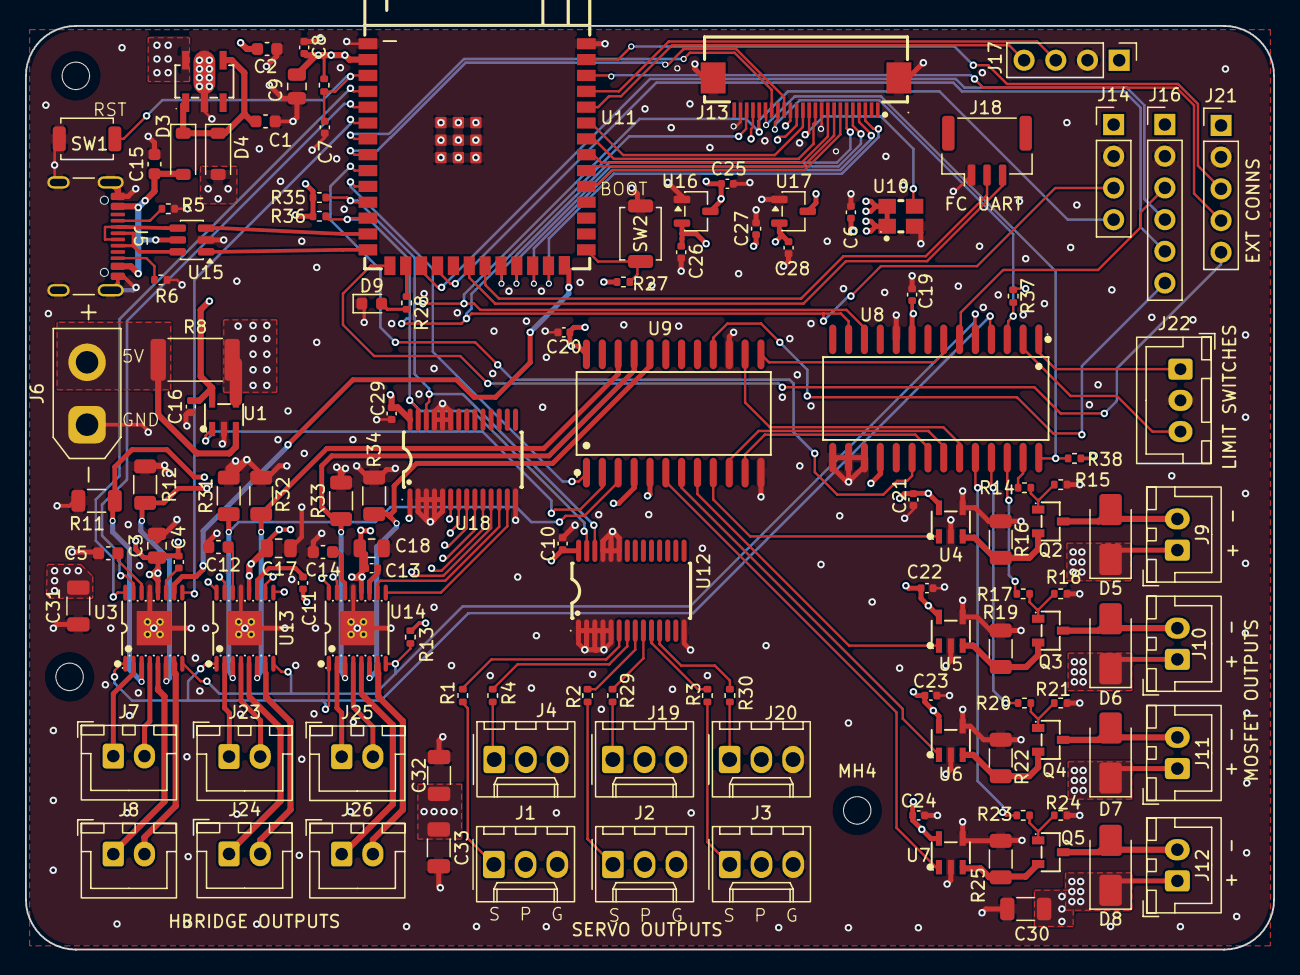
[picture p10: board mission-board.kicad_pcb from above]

Board: 4 copper layers, 100.0 x 74.0 mm, 127 parts (0 on the bottom side), 122 nets.

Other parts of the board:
MH1, MH3, MH4: MountingHole_2.2mm_M2

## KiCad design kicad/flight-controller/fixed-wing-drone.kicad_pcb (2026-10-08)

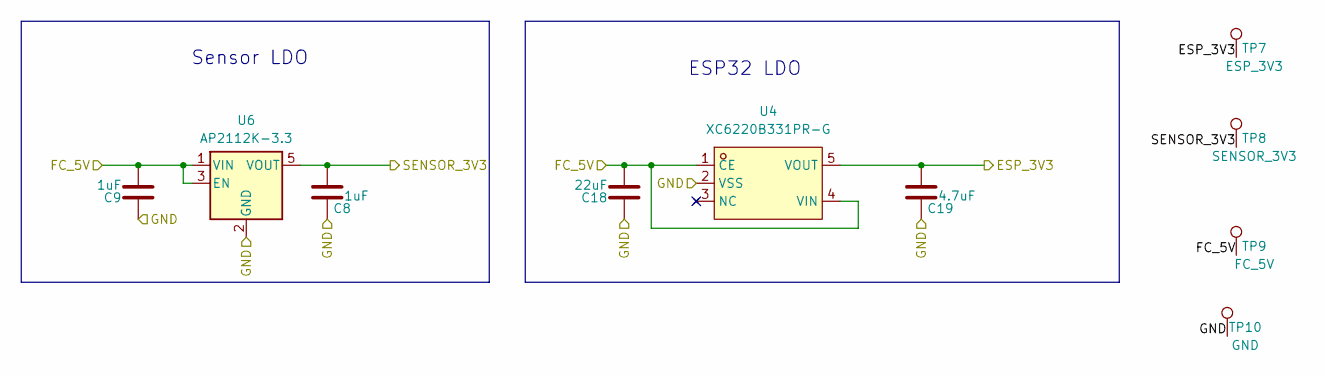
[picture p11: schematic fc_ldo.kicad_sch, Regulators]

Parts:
C8, C9: 1uF; C_0402_1005Metric; LCSC Part C14445
C18: 22uF; C_0805_2012Metric; LCSC Part C45783
C19: 4.7uF; C_0603_1608Metric; LCSC Part C1705
TP7: ESP_3V3; TestPoint_Pad_D1.0mm
TP8: SENSOR_3V3; TestPoint_Pad_D1.0mm
TP9: FC_5V; TestPoint_THTPad_D1.5mm_Drill0.7mm
TP10: GND; TestPoint_THTPad_D1.0mm_Drill0.5mm
U4: XC6220B331PR-G; SOT-89-5_L4.5-W2.5-P1.50-LS4.4-BR; MPN XC6220B331PR-G; LCSC Part C3013658
U6: AP2112K-3.3; SOT-23-5; LCSC Part C51118

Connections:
/ESP_3V3: C19.1, TP7.1 (1_1), U4.5 (VOUT); also elsewhere on the board
/FC_5V: C9.2, C18.2, TP9.1 (1_1), U4.1 (CE), U4.4 (VIN), U6.1 (VIN), U6.3 (EN); also elsewhere on the board
/SENSOR_3V3: C8.1, TP8.1 (1_1), U6.5 (VOUT); also elsewhere on the board
GND: C8.2, C9.1, C18.1, C19.2, TP10.1 (1_1), U4.2 (VSS), U6.2 (GND); also elsewhere on the board

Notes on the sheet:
Sensor LDO
ESP32 LDO

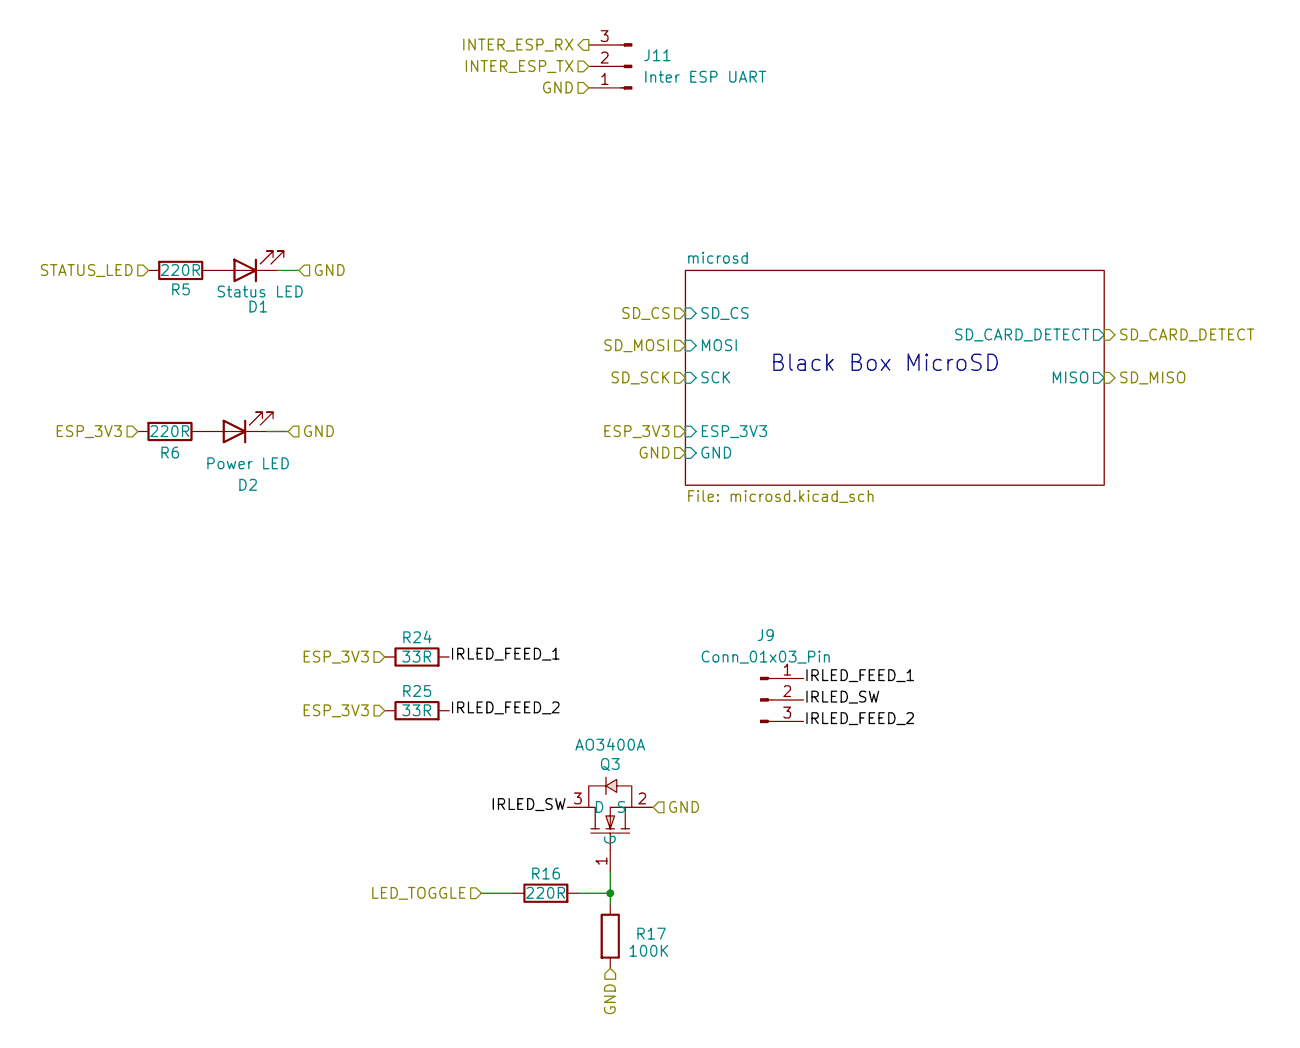
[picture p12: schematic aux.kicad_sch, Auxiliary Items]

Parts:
D1: Status LED; LED_0603_1608Metric; LCSC Part C2289
D2: Power LED; LED_0603_1608Metric; LCSC Part C2286
J9: Conn_01x03_Pin; JST_GH_BM03B-GHS-TBT_1x03-1MP_P1.25mm_Vertical; LCSC Part C161691
J11: Inter ESP UART; JST_GH_BM03B-GHS-TBT_1x03-1MP_P1.25mm_Vertical; LCSC Part C161691
Q3: AO3400A; SOT-23-3_L2.9-W1.3-P1.90-LS2.4-BR; LCSC Part C20917
R5, R6, R16: 220R; R_0402_1005Metric; LCSC Part C25091
R17: 100K; R_0402_1005Metric; LCSC Part C25741
R24, R25: 33R; R_1206_3216Metric; LCSC Part C5759775

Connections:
/ESP_3V3: R6.2, R24.1, R25.1; also elsewhere on the board
/INTER_ESP_RX: J11.3; also elsewhere on the board
/INTER_ESP_TX: J11.2; also elsewhere on the board
/LED_TOGGLE: R16.1; also elsewhere on the board
/STATUS_LED: R5.2; also elsewhere on the board
/aux/IRLED_FEED_1: J9.1, R24.2
/aux/IRLED_FEED_2: J9.3, R25.2
/aux/IRLED_SW: J9.2, Q3.3 (D)
GND: D1.1 (K), D2.1 (K), J11.1, Q3.2 (S), R17.2; also elsewhere on the board
unnamed: D1.2 (A), R5.1
unnamed: D2.2 (A), R6.1
unnamed: Q3.1 (G), R16.2, R17.1

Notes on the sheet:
Black Box MicroSD

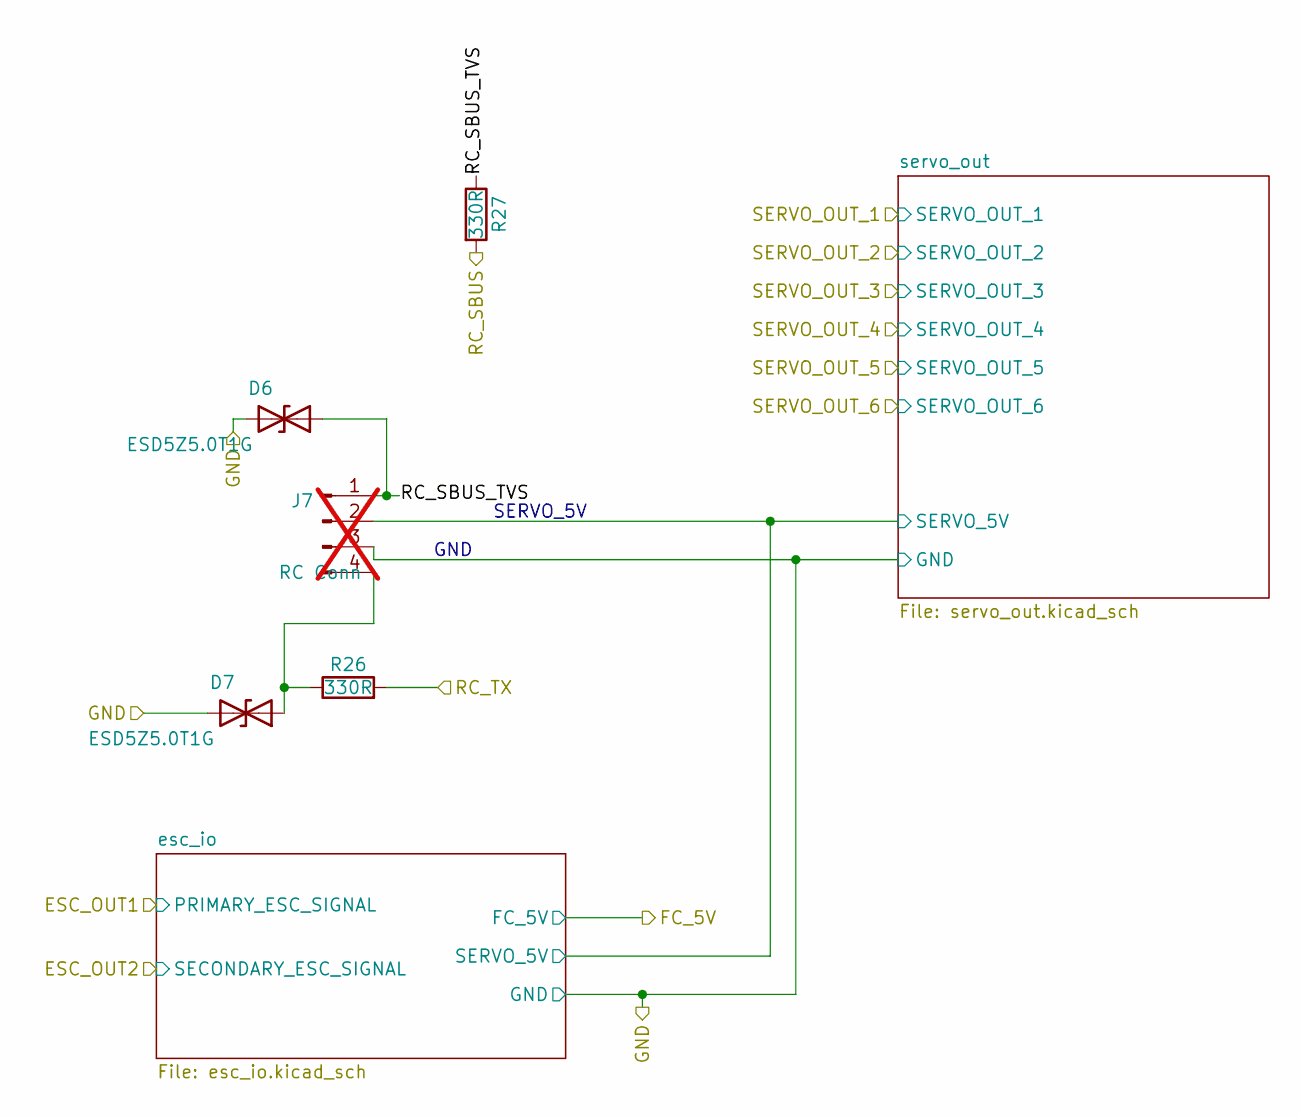
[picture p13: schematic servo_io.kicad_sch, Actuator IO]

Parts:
D6, D7: ESD5Z5.0T1G; D_SOD-523; LCSC Part C82044
J7: RC Conn; Molex_KK-254_AE-6410-04A_1x04_P2.54mm_Vertical; MPN 0022232041; not fitted
R26, R27: 330R; R_0402_1005Metric; LCSC Part C25104

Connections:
/RC_SBUS: R27.2; also elsewhere on the board
/RC_TX: R26.2; also elsewhere on the board
/actuator_io/RC_SBUS_TVS: D6.1 (A1), J7.1, R27.1
/actuator_io/esc_io/SERVO_5V: J7.2; also elsewhere on the board
GND: D6.2 (A2), D7.2 (A2), J7.3; also elsewhere on the board
unnamed: D7.1 (A1), J7.4, R26.1

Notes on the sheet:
SERVO_5V
GND


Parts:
C10: 22uF; C_0805_2012Metric; LCSC Part C45783
C11, C14: 100nF; C_0402_1005Metric; LCSC Part C1525
C12: 1uF; C_0402_1005Metric; LCSC Part C14445
C17: 10uF; C_0805_2012Metric; LCSC Part C440198
D3: B5819W; D_SOD-123; LCSC Part C8598
D4: ESD5Z5.0T1G; D_SOD-523; LCSC Part C82044
J13: USB-C; USB_C_Receptacle_GCT_USB4105-xx-A_16P_TopMnt_Horizontal; LCSC Part C3020560
R3, R4: 5.1K; R_0402_1005Metric; LCSC Part C25905
R7: 10k; R_0402_1005Metric; LCSC Part C25531
R9: 100R; R_0402_1005Metric; LCSC Part C25076
SW1, SW2: TS-1088; SW_SPST_TS-1088-xR020; LCSC Part C720477
U1: ESP32-S3-WROOM-1; WIRELM-SMD_ESP32-S3-WROOM-1; MPN ESP32-S3-WROOM-1-N16R2; LCSC Part C2913205
U5: USBLC6-2SC6; SOT-23-6; MPN USBLC6-2SC6; LCSC Part C7519

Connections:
/BAROMETER_CS: U1.10 (IO17); also elsewhere on the board
/ESC_OUT1: U1.38 (IO2); also elsewhere on the board
/ESC_OUT2: U1.39 (IO1); also elsewhere on the board
/ESP_3V3: C10.1, C11.1, R7.1, U1.2 (3V3); also elsewhere on the board
/FC_5V: D3.1 (K); also elsewhere on the board
/GPS_RX: U1.15 (IO3); also elsewhere on the board
/GPS_TX: U1.17 (IO9); also elsewhere on the board
/IMU1_CS: U1.11 (IO18); also elsewhere on the board
/IMU1_INT: U1.20 (IO12); also elsewhere on the board
/IMU2_ACCEL_CS: U1.8 (IO15); also elsewhere on the board
/IMU2_GYRO_CS: U1.7 (IO7); also elsewhere on the board
/INTER_ESP_RX: U1.5 (IO5); also elsewhere on the board
/INTER_ESP_TX: U1.6 (IO6); also elsewhere on the board
/LED_TOGGLE: U1.26 (IO45); also elsewhere on the board
/MISO: U1.23 (IO21); also elsewhere on the board
/MOSI: U1.24 (IO47); also elsewhere on the board
/RC_SBUS: U1.36 (RXD0); also elsewhere on the board
/RC_TX: U1.37 (TXD0); also elsewhere on the board
/SCK: U1.22 (IO14); also elsewhere on the board
/SCL: U1.19 (IO11); also elsewhere on the board
/SDA: U1.18 (IO10); also elsewhere on the board
/SD_CARD_DETECT: U1.4 (IO4); also elsewhere on the board
/SD_CS: U1.30 (IO37); also elsewhere on the board
/SD_MISO: U1.12 (IO8); also elsewhere on the board
/SD_MOSI: U1.29 (IO36); also elsewhere on the board
/SD_SCK: U1.28 (IO35); also elsewhere on the board
/SERVO_OUT_1: U1.35 (IO42); also elsewhere on the board
/SERVO_OUT_2: U1.34 (IO41); also elsewhere on the board
/SERVO_OUT_3: U1.32 (IO39); also elsewhere on the board
/SERVO_OUT_4: U1.25 (IO48); also elsewhere on the board
/SERVO_OUT_5: U1.33 (IO40); also elsewhere on the board
/SERVO_OUT_6: U1.31 (IO38); also elsewhere on the board
/STATUS_LED: U1.16 (IO46); also elsewhere on the board
/UWB_CS: U1.9 (IO16); also elsewhere on the board
/UWB_INT: U1.21 (IO13); also elsewhere on the board
/esp32s3/BOOT: R9.1, U1.27 (IO0)
/esp32s3/DATA+: J13.A6 (D+), J13.B6 (D+), U1.14 (IO20), U5.1 (I/O1), U5.6 (I/O1)
/esp32s3/DATA-: J13.A7 (D-), J13.B7 (D-), U1.13 (IO19), U5.3 (I/O2), U5.4 (I/O2)
/esp32s3/EN: C12.1, C14.1, R7.2, SW1.1, U1.3 (EN)
/esp32s3/USB_VBUS: C17.1, D3.2 (A), D4.1 (A1), J13.A4 (VBUS), J13.A9 (VBUS), J13.B4 (VBUS), J13.B9 (VBUS), U5.5 (VBUS)
GND: C10.2, C11.2, C12.2, C14.2, C17.2, D4.2 (A2), J13.A1 (GND), J13.A12 (GND), J13.B1 (GND), J13.B12 (GND), J13.SH (SHIELD), R3.1, R4.1, SW1.2, SW2.2, U1.1 (GND), U1.40 (GND), U1.41 (GND), U5.2 (GND); also elsewhere on the board
unnamed: J13.A5 (CC1), R3.2
unnamed: J13.B5 (CC2), R4.2
unnamed: R9.2, SW2.1

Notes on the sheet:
Boot Button
Reset Button
USB-C


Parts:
J8: LIDAR I2C; Molex_PicoBlade_53398-0471_1x04-1MP_P1.25mm_Vertical; LCSC Part C17617036
J10: UWB SPI; JST_GH_BM07B-GHS-TBT_1x07-1MP_P1.25mm_Vertical; LCSC Part C378970
J14: GPS/Compass; JST_GH_BM06B-GHS-TBT_1x06-1MP_P1.25mm_Vertical; LCSC Part C189892
J15: Airspeed I2C; JST_GH_BM04B-GHS-TBT_1x04-1MP_P1.25mm_Vertical; LCSC Part C161692
L1, L2, L3, L4: Ferrite Bead; L0603; MPN BLM18PG121SN1D; LCSC Part C14709
R20, R21: 4.7K; R_0402_1005Metric; LCSC Part C25900
TP5: SDA; TestPoint_THTPad_D1.0mm_Drill0.5mm
TP6: SCL; TestPoint_THTPad_D1.0mm_Drill0.5mm

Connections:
/FC_5V: L1.2, L2.1, L3.1, L4.1; also elsewhere on the board
/GPS_RX: J14.3; also elsewhere on the board
/GPS_TX: J14.4; also elsewhere on the board
/MISO: J10.3; also elsewhere on the board
/MOSI: J10.2; also elsewhere on the board
/SCK: J10.4; also elsewhere on the board
/SCL: J8.2, J14.6, J15.2, R21.1, TP6.1 (1_1); also elsewhere on the board
/SDA: J8.3, J14.1, J15.3, R20.1, TP5.1 (1_1); also elsewhere on the board
/SENSOR_3V3: R20.2, R21.2; also elsewhere on the board
/UWB_CS: J10.5; also elsewhere on the board
/UWB_INT: J10.6; also elsewhere on the board
GND: J8.4, J10.7, J14.2, J15.4; also elsewhere on the board
unnamed: J8.1, L2.2
unnamed: J10.1, L3.2
unnamed: J14.5, L1.1
unnamed: J15.1, L4.2

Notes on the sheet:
I2C - SCL - SDA
UART (gps) - RX - TX I2C (compass) - SCL - SDA
SPI - SCK - MOSI - MISO - CS


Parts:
C1, C4, C5: 100nF; C_0402_1005Metric; LCSC Part C1525
C2: 2.2 uF; C_0603_1608Metric; LCSC Part C23630
C3: 10 nF; C_0402_1005Metric; LCSC Part C15195
TP1: MOSI; TestPoint_THTPad_D1.0mm_Drill0.5mm
TP2: MISO; TestPoint_THTPad_D1.0mm_Drill0.5mm
TP3: SCK; TestPoint_THTPad_D1.0mm_Drill0.5mm
TP4: GND; TestPoint_THTPad_D1.5mm_Drill0.7mm
U2: Primary IMU; LGA-14_L3.0-W2.5-P0.50-TL; MPN ICM-42688-P; LCSC Part C1850418
U3: Backup IMU; LGA-16_L4.5-W3.0-P0.50-BL; MPN BMI088; LCSC Part C194919

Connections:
/IMU1_CS: U2.12 (AP_CS); also elsewhere on the board
/IMU1_INT: U2.4 (INT1/INT); also elsewhere on the board
/IMU2_ACCEL_CS: U3.14 (CSB1); also elsewhere on the board
/IMU2_GYRO_CS: U3.5 (CSB2); also elsewhere on the board
/MISO: TP2.1 (1_1), U2.1 (AP_SDO/AP_AD0), U3.10 (SDO2), U3.15 (SDO1); also elsewhere on the board
/MOSI: TP1.1 (1_1), U2.14 (AP_SDA/AP_SDIO/AP_SDI), U3.9 (SDA/SDI); also elsewhere on the board
/SCK: TP3.1 (1_1), U2.13 (AP_SCL/AP_SCLK), U3.8 (SCL/SCK); also elsewhere on the board
/SENSOR_3V3: C1.1, C2.1, C3.1, C4.1, C5.1, U2.5 (VDDIO), U2.8 (VDD), U3.3 (VDD), U3.11 (VDDIO); also elsewhere on the board
GND: C1.2, C2.2, C3.2, C4.2, C5.2, TP4.1 (1_1), U2.6 (GND), U2.7 (RESV), U2.11 (RESV), U3.2 (NC), U3.4 (GNDA), U3.6 (GNDIO), U3.7 (PS); also elsewhere on the board

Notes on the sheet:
SPI - SCK - MOSI - MISO - CSB1 (accel) - CSB2 (gyro)
SPI - SCK - MOSI - MISO - CS


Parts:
C15, C16: 100nF; C_0402_1005Metric; LCSC Part C1525
U7: Barometer; LGA-8_L2.5-W2.0-P0.65-TR_DPS368; MPN DPS368XTSA1; LCSC Part C3232508

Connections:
/BAROMETER_CS: U7.2 (CSB); also elsewhere on the board
/MISO: U7.5 (SDO); also elsewhere on the board
/MOSI: U7.3 (SDI); also elsewhere on the board
/SCK: U7.4 (SCK); also elsewhere on the board
/SENSOR_3V3: C15.2, C16.1, U7.6 (VDDIO), U7.8 (VDD); also elsewhere on the board
GND: C15.1, C16.2, U7.1 (GND), U7.7 (GND); also elsewhere on the board

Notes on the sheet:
SPI - SCK - MOSI - MISO - CS


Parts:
C13: 100nF; C_0402_1005Metric; LCSC Part C1525
Card1: MicroSD; TF-SMD_XKTF-001B; MPN XKTF-001B; LCSC Part C381080
R1, R2, R11, R28, R29, R30: 10K; R_0402_1005Metric; LCSC Part C25531

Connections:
/ESP_3V3: C13.2, Card1.4 (VDD), R1.1, R2.1, R11.1, R28.2, R29.2, R30.2; also elsewhere on the board
/SD_CARD_DETECT: Card1.9 (CARD-DETECT), R11.2; also elsewhere on the board
/SD_CS: Card1.2 (CD/DAT3), R29.1; also elsewhere on the board
/SD_MISO: Card1.7 (DAT0), R28.1; also elsewhere on the board
/SD_MOSI: Card1.3 (CMD), R30.1; also elsewhere on the board
/SD_SCK: Card1.5 (CLK); also elsewhere on the board
GND: C13.1, Card1.6 (VSS), Card1.10 (GND), Card1.11 (SHELL), Card1.12 (SHELL); also elsewhere on the board
unnamed: Card1.8 (DAT1), R2.2
unnamed: Card1.1 (DAT2), R1.2

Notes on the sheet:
SPI Mode - SCK - MOSI - MISO - CS

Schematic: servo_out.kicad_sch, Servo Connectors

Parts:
J1: 1; Molex_KK-254_AE-6410-03A_1x03_P2.54mm_Vertical; not fitted
J2: 2; Molex_KK-254_AE-6410-03A_1x03_P2.54mm_Vertical; not fitted
J3: 3; Molex_KK-254_AE-6410-03A_1x03_P2.54mm_Vertical; not fitted
J4: 4; Molex_KK-254_AE-6410-03A_1x03_P2.54mm_Vertical; not fitted
J5: 5; Molex_KK-254_AE-6410-03A_1x03_P2.54mm_Vertical; not fitted
J6: 6; Molex_KK-254_AE-6410-03A_1x03_P2.54mm_Vertical; not fitted
R12, R13, R14, R15, R18, R19: 330R; R_0402_1005Metric; LCSC Part C25104

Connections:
/SERVO_OUT_1: R12.1; also elsewhere on the board
/SERVO_OUT_2: R13.1; also elsewhere on the board
/SERVO_OUT_3: R14.1; also elsewhere on the board
/SERVO_OUT_4: R19.1; also elsewhere on the board
/SERVO_OUT_5: R18.1; also elsewhere on the board
/SERVO_OUT_6: R15.1; also elsewhere on the board
/actuator_io/esc_io/SERVO_5V: J1.2, J2.2, J3.2, J4.2, J5.2, J6.2; also elsewhere on the board
GND: J1.3, J2.3, J3.3, J4.3, J5.3, J6.3; also elsewhere on the board
unnamed: J1.1, R12.2
unnamed: J2.1, R13.2
unnamed: J3.1, R14.2
unnamed: J4.1, R19.2
unnamed: J5.1, R18.2
unnamed: J6.1, R15.2

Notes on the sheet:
Output 4
Output 2
Output 1
Output 6
Output 3
Output 5

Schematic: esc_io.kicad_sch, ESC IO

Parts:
C20: 22uF; C_0805_2012Metric; LCSC Part C45783
D5: B5819W; D_SOD-123; LCSC Part C8598
J19: ESC2; Molex_KK-254_AE-6410-03A_1x03_P2.54mm_Vertical; not fitted
J20: FC UBEC Input; Molex_KK-254_AE-6410-03A_1x03_P2.54mm_Vertical; not fitted
J22: ESC1; Molex_KK-254_AE-6410-03A_1x03_P2.54mm_Vertical; not fitted
R22, R23: 330R; R_0402_1005Metric; LCSC Part C25104

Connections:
/ESC_OUT1: R23.2; also elsewhere on the board
/ESC_OUT2: R22.2; also elsewhere on the board
/FC_5V: D5.1 (K); also elsewhere on the board
/actuator_io/esc_io/SERVO_5V: C20.1, J22.2; also elsewhere on the board
GND: C20.2, J19.3, J20.1, J20.3, J22.3; also elsewhere on the board
unnamed: D5.2 (A), J20.2
unnamed: J19.1, R22.1
unnamed: J22.1, R23.1

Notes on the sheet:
GND
VCC
Only takes 5v from ESC1 to control servos. Doing power OR'ing is not worth it. ESC2 5v line is NC.


Board: 4 copper layers, 91.0 x 61.5 mm, 101 parts (0 on the bottom side), 69 nets.

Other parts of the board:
FID1, FID2, FID3: Fiducial_1mm_Mask2mm
H1, H2, H3: MountingHole_2.2mm_M2

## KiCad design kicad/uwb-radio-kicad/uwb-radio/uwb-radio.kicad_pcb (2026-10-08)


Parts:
C1: 22uF; C_0805_2012Metric_Pad1.18x1.45mm_HandSolder; MPN CL21A226MAQNNNE; LCSC Part C45783
C2: 10uF; C_0805_2012Metric_Pad1.18x1.45mm_HandSolder; MPN CL21A106KAYNNNE; LCSC Part C15850
CN1: BM07B-GHS-TBT; CONN-SMD_7P-P1.25_BM07B-GHS-TBT-LF-SN-N; MPN BM07B-GHS-TBT(LF)(SN)(N); LCSC Part C378970
H1, H2: MountingHole_M2; MountingHole_2.2mm_M2
R1: 100K; R_0402_1005Metric_Pad0.72x0.64mm_HandSolder; MPN RC0402FR-07100KL; DigiKey PN 311-100KLRCT-ND
R2: 33R; R_0603_1608Metric_Pad0.98x0.95mm_HandSolder
U1: DWM3000TR13; WIRELM-SMD_DWM3000TR13; MPN DWM3000TR13; LCSC Part C5299931
U2: XC6220B331PR-G; SOT-89-5_L4.5-W2.5-P1.50-LS4.4-BR; MPN XC6220B331PR-G; LCSC Part C3013658

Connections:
+3V3: C2.1, U1.5 (VDD1), U1.6 (VDD3V3), U1.7 (VDD3V3), U2.5 (VOUT)
+5V: C1.1, CN1.1, U2.1 (CE), U2.4 (VIN)
/CS: CN1.5, U1.17 (SPICSn)
/INT: CN1.6, R1.1, U1.22 (GPIO8)
/MISO: CN1.3, R2.2
/MOSI: CN1.2, U1.18 (SPIMOSI)
/SCK: CN1.4, U1.20 (SPICLK)
GND: C1.2, C2.2, CN1.7, CN1.8, CN1.9, R1.2, U1.2 (WAKEUP), U1.8 (VSS), U1.16 (VSS), U1.21 (VSS), U1.23 (VSS), U1.24 (VSS), U2.2 (VSS)
unnamed: R2.1, U1.19 (SPIMISO)


Board: 2 copper layers, 21.5 x 27.5 mm, 9 parts (0 on the bottom side), 9 nets.

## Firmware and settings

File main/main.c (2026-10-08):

#include <math.h>
#include <stdio.h>
#include "freertos/FreeRTOS.h"
#include "freertos/task.h"
#include "freertos/semphr.h"
#include "driver/gpio.h"
#include "esp_log.h"
#include "esp_timer.h"
#include "driver/mcpwm_prelude.h"
#include "pwm_output.h"
#include "rc_capture.h"
#include "imu.h"
#include "gps.h"
#include "pid.h"
#include "nav.h"
#include "airspeed.h"
#include "config_store.h"
#include "i2c_bus.h"
#include "output_ctl.h"
#include "setup_mode.h"
#include "flight_log.h"

static const char *TAG = "MAIN";

#define CONTROL_TASK_HZ (100)
#define CONTROL_TASK_MS (1000 / CONTROL_TASK_HZ)

#define SERVO_TIMEBASE_RESOLUTION_HZ 1000000  // 1MHz, 1us per tick
#define SERVO_TIMEBASE_PERIOD        20000    // 20000 ticks, 20ms

#define CAPTURE_RESOLUTION (80000000) // This is unchangeable on the esp32s3, so its always 80MHz

// GPIO assignments for RC receiver inputs, confirmed against the v2.1 board
// pinout (GPIO 35/36/37 are NC on this board -- not usable for anything).
#define CH1_IN_GPIO  GPIO_NUM_9
#define CH2_IN_GPIO  GPIO_NUM_38
#define CH3_IN_GPIO  GPIO_NUM_14
#define CH4_IN_GPIO  GPIO_NUM_21
#define CH5_IN_GPIO  GPIO_NUM_7
#define CH6_IN_GPIO  GPIO_NUM_8

// GPIO assignments for outputs to the peripherals
#define CH1_OUT_GPIO  GPIO_NUM_17
#define CH2_OUT_GPIO  GPIO_NUM_18
#define CH3_OUT_GPIO  GPIO_NUM_46
#define CH4_OUT_GPIO  GPIO_NUM_45
#define CH5_OUT_GPIO  GPIO_NUM_48
#define CH6_OUT_GPIO  GPIO_NUM_47

// Dedicated ESC/motor outputs -- separate physical connectors from the 6
// channels above. Confirmed against the v2.1 board pinout (the KiCad
// sources in this repo are a future v3.1 revision and don't reflect it).
#define ESC1_OUT_GPIO GPIO_NUM_16
#define ESC2_OUT_GPIO GPIO_NUM_15

// NUM_RC_CHANNELS, NUM_OUTPUT_CHANNELS, CH*_NUM, RC_*, and ESC1_CH/ESC2_CH
// channel-index macros live in output_ctl.h now, shared with setup_mode.c.

// Airframe control-surface layout is now a runtime setting (g_airframe_mode,
// loaded from NVS at boot) instead of this compile-time define -- see
// AIRFRAME_CONVENTIONAL/AIRFRAME_AILEVON_MODE in config_store.h.

static output_group_t out_groups[SOC_MCPWM_GROUPS];
static rc_capture_group_t cap_groups[SOC_MCPWM_GROUPS];

// Per-output-channel calibrated PWM range + reversal, loaded from NVS at
// boot (config_store.h's output_cfg_t), defaulting to PULSEWIDTH_DEFAULT_MIN/
// MAX_US with reversed=false when nothing is persisted yet. See
// channel_output_type()/apply_output_cfg() below. Sized for all 8 output
// channels (6 RC-mirrored + ESC1 + ESC2), not just NUM_RC_CHANNELS.
static output_cfg_t channel_cfgs[NUM_OUTPUT_CHANNELS];

// Last pulse width actually written for each logical output channel, after
// reversal and clipping -- what the servo/ESC is really being sent, as
// opposed to the RC input it was derived from. 0 until first written.
// Reported by the setup-mode API so reversal/range/mapping can be verified
// on screen, not just by watching the servo.
static volatile uint16_t last_output_us[NUM_OUTPUT_CHANNELS];

// Which physical RC input pin (capture-channel index, 0-5) each logical
// RC_* function actually reads from -- see config_store.h's
// rc_input_map_cfg_t. Defaults to the identity mapping (matching this
// project's compiled-in default channel order: RC_AILERON=CH1,
// RC_ELEVATOR=CH2, RC_THROTTLE=CH3, RC_DIAL=CH4, RC_RUDDER=CH5,
// RC_SWITCH=CH6), overridable from setup mode for a receiver whose channel
// order doesn't match, without re-wiring anything.
static uint8_t rc_input_map[NUM_RC_CHANNELS] = {0, 1, 2, 3, 4, 5};

// Which physical servo output pin (0-5 = CH1_OUT_GPIO..CH6_OUT_GPIO) each
// logical RC_* function drives -- see config_store.h's
// servo_output_map_cfg_t. Defaults to the identity mapping (aileron on
// servo_out_1, etc.), overridable from setup mode. Always a permutation.
static uint8_t servo_output_map[NUM_RC_CHANNELS] = {0, 1, 2, 3, 4, 5};

// Autonomous-mode trim centres -- see config_store.h's trim_cfg_t and
// output_ctl.h's TRIM_* bounds. Filled with TRIM_NEUTRAL_US in app_main()
// before any persisted override is loaded.
static trim_cfg_t g_trim_cfg;

static airframe_mode_t g_airframe_mode = AIRFRAME_CONVENTIONAL;

// Single vs twin motor, and which physical ESC connector is "left" when
// twin. Defaults to a single motor on ESC1 -- see apply_throttle_to_escs().
static motor_cfg_t g_motor_cfg = { .motor_count = 1, .esc1_is_left = true };

// Target cruise airspeed (target_cms) for AIRSPEED_PID_CFG, and the throttle
// fraction (fallback_pct) used when no airspeed sensor reading is available
// at all. Loaded from NVS at boot; these defaults match the previous
// compile-time AIRSPEED_TARGET_CMS placeholder and the user's spec of a 75%
// cruise fallback.
static airspeed_cfg_t g_airspeed_cfg = { .target_cms = 1000.0f, .fallback_pct = 0.75f };

// i_limit=250 reserves at least half of the actuator's +/-500us range
// (SERVO_MIN/MAX_PULSEWIDTH_US relative to MIDDLE_SERVO_VAL) for P/D, so a
// wound-up I-term can't eat the whole output on its own. Placeholder like the
// gains themselves; re-tune once k_i is actually set to something nonzero.
// SITL-validated (sitl/nav_sim.exe + sitl/sitl_sim.exe, see sitl/README.md):
// k_p=10 k_d=0.3 -- this project's gains before this pass -- is only stable
// for small corrections; it diverges under a full-authority step (the ±45deg
// commanded by set_goal_roll_deg's clamp, which the new waypoint-following
// nav_task actually issues in practice, not just small disturbance recovery).
// k_p=5 k_d=0.4 was the most aggressive gain that stayed stable across the
// entire commanded range (10/20/30/45deg steps, both signs) AND across 20
// noise seeds at up to 2deg IMU noise stddev -- higher k_p consistently
// failed the noise sweep before it failed the clean-signal sweep.
pid_cfg_t ROLL_PID_CFG = {
    .k_p = 5,
    .k_i = 0,
    .k_d = 0.4,
    .i_limit = 250,
    .integral = 0,
    .last_err = 0,
    .first = true
};

// Same SITL sweep as ROLL_PID_CFG, run separately against the pitch axis's
// own plant model (it has a nonzero restoring term -- see sitl/plant.h --
// unlike roll) and its own ±20deg commanded range. Same winning gain.
pid_cfg_t PITCH_PID_CFG = {
    .k_p = 5,
    .k_i = 0,
    .k_d = 0.4,
    .i_limit = 250,
    .integral = 0,
    .last_err = 0,
    .first = true
};

// Desk-derived, not SITL-validated like ROLL/PITCH_PID_CFG above -- there's
// no airspeed plant model (thrust curve, drag, mass) to sweep against yet.
// This replaces an untested k_p=5 placeholder with a number grounded in the
// MS4525DO's own accuracy spec instead of a guess; still needs real bench/
// flight tuning.
//
// The sensor's +-0.25%-of-span spec is +-0.005 PSI (+-34Pa) of noise on the
// underlying differential-pressure reading, filtered here (see
// AIRSPEED_FILTER_ALPHA in airspeed.c) down to roughly a 4x std-dev
// reduction -- but noise on a *pressure* reading translates to noise on the
// *speed* it implies (dv/dp = 1/(rho*v)) that shrinks with airspeed, not a
// fixed cm/s figure. At g_airspeed_cfg's default 1000cm/s (10m/s) cruise
// target, that's dp =~ 61Pa for the target speed itself -- comparable to the
// sensor's own noise floor -- giving an estimated post-filter residual noise
// of roughly +-65cm/s even at cruise (worse nearer zero airspeed, where the
// same pressure noise implies a larger speed swing).
//
// Sizing k_p so that residual noise alone doesn't swamp the output: the
// throttle channel's usable PWM range is ~1000us (SERVO_MIN/MAX_PULSEWIDTH_US
// via channel_cfgs[ESC1_CH]), so k_p=2 keeps noise-driven throttle
// chatter to roughly +-130us (2 * 65cm/s) -- a small, tolerable fraction of
// that range -- while still giving a real 2m/s (200cm/s) airspeed error 400us
// of correction, which is a meaningful, not negligible, throttle response.
pid_cfg_t AIRSPEED_PID_CFG = {
    .k_p = 2,
    .k_i = 0,
    .k_d = 0,
    .i_limit = 250,
    .integral = 0,
    .last_err = 0,
    .first = true
};

// Conservative caps on commanded attitude. Retune once the airframe is
// flight-characterized / tested. These exist so nothing (i.e. a bug)
// can command a full 180 degree pitch through set_goal_roll_deg/set_goal_pitch_deg;
#define MAX_ROLL_GOAL_DEG  45.0f
#define MAX_PITCH_GOAL_DEG 20.0f

// Pitch attitude held during the failsafe spiral descent (motors off, see
// nav.h's NAV_FAILSAFE_DESCEND). Slightly nose-down so the glide keeps
// enough airspeed in the bank instead of the pitch loop holding the nose up
// into a stall. Not SITL-validated -- worth confirming on a real airframe.
#define FAILSAFE_DESCENT_PITCH_DEG (-5.0f)

static float clampf(float v, float lo, float hi) {
    if (v < lo) return lo;
    if (v > hi) return hi;
    return v;
}

float goal_roll_deg = 0.0f;
float goal_pitch_deg = 0.0f;

void set_goal_roll_deg(float deg) {
    goal_roll_deg = clampf(deg, -MAX_ROLL_GOAL_DEG, MAX_ROLL_GOAL_DEG);
}

void set_goal_pitch_deg(float deg) {
    goal_pitch_deg = clampf(deg, -MAX_PITCH_GOAL_DEG, MAX_PITCH_GOAL_DEG);
}

// Merges the fields marked present in `fields_present` (a pid_field_mask_t
// bitmask) into *cfg's live gains, leaving absent fields untouched, then
// persists the merged 4-gain result to NVS under `nvs_key`. No mutex needed:
// these three PID configs are only ever read inside update_autonomous_outputs(),
// which never runs concurrently with a setup-mode HTTP request -- flight mode
// and setup mode are mutually exclusive per boot (see the boot-time branch in
// app_main()).
static bool apply_pid_field_update(pid_cfg_t *cfg, const char *nvs_key, uint8_t fields_present, const pid_gains_t *g) {
    if (fields_present & PID_FIELD_KP)     cfg->k_p = g->k_p;
    if (fields_present & PID_FIELD_KI)     cfg->k_i = g->k_i;
    if (fields_present & PID_FIELD_KD)     cfg->k_d = g->k_d;
    if (fields_present & PID_FIELD_ILIMIT) cfg->i_limit = g->i_limit;
    pid_gains_t merged = { cfg->k_p, cfg->k_i, cfg->k_d, cfg->i_limit };
    return config_store_save_pid_gains(nvs_key, &merged) == ESP_OK;
}

bool set_roll_pid_gains(uint8_t fields_present, const pid_gains_t *g) {
    return apply_pid_field_update(&ROLL_PID_CFG, "pid_roll", fields_present, g);
}

bool set_pitch_pid_gains(uint8_t fields_present, const pid_gains_t *g) {
    return apply_pid_field_update(&PITCH_PID_CFG, "pid_pitch", fields_present, g);
}

bool set_airspeed_pid_gains(uint8_t fields_present, const pid_gains_t *g) {
    return apply_pid_field_update(&AIRSPEED_PID_CFG, "pid_aspd", fields_present, g);
}

pid_gains_t get_roll_pid_gains(void) {
    return (pid_gains_t){ ROLL_PID_CFG.k_p, ROLL_PID_CFG.k_i, ROLL_PID_CFG.k_d, ROLL_PID_CFG.i_limit };
}

pid_gains_t get_pitch_pid_gains(void) {
    return (pid_gains_t){ PITCH_PID_CFG.k_p, PITCH_PID_CFG.k_i, PITCH_PID_CFG.k_d, PITCH_PID_CFG.i_limit };
}

pid_gains_t get_airspeed_pid_gains(void) {
    return (pid_gains_t){ AIRSPEED_PID_CFG.k_p, AIRSPEED_PID_CFG.k_i, AIRSPEED_PID_CFG.k_d, AIRSPEED_PID_CFG.i_limit };
}

bool autonomous_mode_enabled(uint32_t mode_us) {
    return (mode_us < 1500);
}

/* INPUT CONVERSIONS (2 groups with 3 capture channels each) */

/**
 * Convert rc channel number to capture channel number
 * The ch parameter should be 0-indexed (subtract 1 from it before passing in) 
*/
int rc_channel_to_capture_channel(int ch)
{
    if (ch < 0 || ch >= NUM_RC_CHANNELS) { ESP_LOGE(TAG, "Invalid channel number: %d; should be in [0, %d)", ch, NUM_RC_CHANNELS); abort(); }
    return ch % MCPWM_CAPTURE_CHANNELS_PER_GROUP; 
}

/**
 * Convert rc channel number to capture group number
 * The ch parameter should be 0-indexed (subtract 1 from it before passing in) 
*/
int rc_channel_to_capture_group(int ch)
{
    if (ch < 0 || ch >= NUM_RC_CHANNELS) { ESP_LOGE(TAG, "Invalid channel number: %d; should be in [0, %d)", ch, NUM_RC_CHANNELS); abort(); }
    return ch / MCPWM_CAPTURE_CHANNELS_PER_GROUP;
}

/* OUTPUT CONVERSIONS (2 groups with 3 operators each, with each operator having 2 triggers) */

/**
 * Convert output channel number to output group number
 * The ch parameter should be 0-indexed (subtract 1 from it before passing in)
*/
int rc_channel_to_output_group(int ch)
{
    if (ch < 0 || ch >= NUM_OUTPUT_CHANNELS) { ESP_LOGE(TAG, "Invalid output channel number: %d; should be in [0, %d)", ch, NUM_OUTPUT_CHANNELS); abort(); }
    return ch / MCPWM_TRIGGERS_PER_GROUP;
}

/**
 * Convert output channel number to output operator number (local to its own
 * group -- e.g. channel 6 is the first channel of group 1, not the 4th
 * operator of a single flat sequence, so the channel index is first reduced
 * to its position within its own group before dividing).
 * The ch parameter should be 0-indexed (subtract 1 from it before passing in)
*/
int rc_channel_to_output_op(int ch)
{
    if (ch < 0 || ch >= NUM_OUTPUT_CHANNELS) { ESP_LOGE(TAG, "Invalid output channel number: %d; should be in [0, %d)", ch, NUM_OUTPUT_CHANNELS); abort(); }
    int local_ch = ch % MCPWM_TRIGGERS_PER_GROUP;
    return local_ch / SOC_MCPWM_GENERATORS_PER_OPERATOR;
}

/**
 * Convert output channel number to output comparator / generator number
 * (also local to its own group -- see rc_channel_to_output_op()).
 * The ch parameter should be 0-indexed (subtract 1 from it before passing in)
*/
int rc_channel_to_output_cmpr(int ch)
{
    if (ch < 0 || ch >= NUM_OUTPUT_CHANNELS) { ESP_LOGE(TAG, "Invalid output channel number: %d; should be in [0, %d)", ch, NUM_OUTPUT_CHANNELS); abort(); }
    int local_ch = ch % MCPWM_TRIGGERS_PER_GROUP;
    return local_ch % SOC_MCPWM_COMPARATORS_PER_OPERATOR;
}
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
void app_main(void)
{
    // Nothing slow may run before io_hardware_init() + the pass-through in
    // setup_mode_requested() below: this path is also an in-air brownout
    // recovery, and every millisecond here is a millisecond the pilot has
    // no control surfaces. Only the fast NVS loads the pass-through itself
    // depends on (calibration, channel maps) go first.

    // First: records why we (re)booted -- e.g. a brownout mid-flight --
    // before anything else can go wrong. RAM-only, no NVS needed.
    flight_log_boot();

    // Must run before anything else touches NVS (config_store.c, and
    // nav_init()'s own persisted-mission/heading-PID load below).
    ESP_ERROR_CHECK(config_store_init());

    // Override compiled-in PID defaults with whatever was last persisted via
    // setup mode, if anything. HEADING_PID_CFG's own load happens inside
    // nav_init() itself, since it's nav.c's own private state.
    pid_gains_t g;
    if (config_store_load_pid_gains("pid_roll", &g)) {
        ROLL_PID_CFG.k_p = g.k_p; ROLL_PID_CFG.k_i = g.k_i; ROLL_PID_CFG.k_d = g.k_d; ROLL_PID_CFG.i_limit = g.i_limit;
        ESP_LOGI(TAG, "Loaded persisted roll PID gains from NVS");
    }
    if (config_store_load_pid_gains("pid_pitch", &g)) {
        PITCH_PID_CFG.k_p = g.k_p; PITCH_PID_CFG.k_i = g.k_i; PITCH_PID_CFG.k_d = g.k_d; PITCH_PID_CFG.i_limit = g.i_limit;
        ESP_LOGI(TAG, "Loaded persisted pitch PID gains from NVS");
    }
    if (config_store_load_pid_gains("pid_aspd", &g)) {
        AIRSPEED_PID_CFG.k_p = g.k_p; AIRSPEED_PID_CFG.k_i = g.k_i; AIRSPEED_PID_CFG.k_d = g.k_d; AIRSPEED_PID_CFG.i_limit = g.i_limit;
        ESP_LOGI(TAG, "Loaded persisted airspeed PID gains from NVS");
    }

    // Per-channel output range/reversal: default to the standard 1000-2000us
    // range with reversed=false when nothing is persisted yet -- setup mode
    // can widen this up to PULSEWIDTH_ABS_MIN/MAX_US per channel. Covers all
    // 8 output channels (6 RC-mirrored + ESC1 + ESC2).
    for (int ch = 0; ch < NUM_OUTPUT_CHANNELS; ch++) {
        channel_cfgs[ch].min_us = PULSEWIDTH_DEFAULT_MIN_US;
        channel_cfgs[ch].max_us = PULSEWIDTH_DEFAULT_MAX_US;
        channel_cfgs[ch].reversed = false;

        char key[16];
        snprintf(key, sizeof(key), "outcfg%d", ch + 1);
        output_cfg_t loaded;
        if (config_store_load_output_cfg(key, &loaded)) {
            channel_cfgs[ch] = loaded;
            ESP_LOGI(TAG, "Loaded persisted output cfg for channel %d from NVS", ch + 1);
        }
    }

    for (int ch = 0; ch < TRIM_CHANNELS; ch++) {
        g_trim_cfg.center_us[ch] = TRIM_NEUTRAL_US;
    }
    trim_cfg_t loaded_trim;
    if (config_store_load_trim_cfg(&loaded_trim)) {
        // Per-channel, so one corrupt entry doesn't throw away the others.
        for (int ch = 0; ch < TRIM_CHANNELS; ch++) {
            if (trim_channel_allowed(ch) && trim_in_bounds(loaded_trim.center_us[ch])) {
                g_trim_cfg.center_us[ch] = loaded_trim.center_us[ch];
            } else if (trim_channel_allowed(ch)) {
                ESP_LOGW(TAG, "Persisted trim for channel %d out of bounds (%u us), using %d",
                         ch + 1, loaded_trim.center_us[ch], TRIM_NEUTRAL_US);
            }
        }
        ESP_LOGI(TAG, "Loaded persisted trim from NVS");
    }

    airframe_mode_t loaded_airframe_mode;
    if (config_store_load_airframe_mode(&loaded_airframe_mode)) {
        g_airframe_mode = loaded_airframe_mode;
        ESP_LOGI(TAG, "Loaded persisted airframe mode from NVS: %d", (int)g_airframe_mode);
    }

    airspeed_cfg_t loaded_airspeed_cfg;
    if (config_store_load_airspeed_cfg(&loaded_airspeed_cfg)) {
        g_airspeed_cfg = loaded_airspeed_cfg;
        ESP_LOGI(TAG, "Loaded persisted airspeed cfg from NVS");
    }

    motor_cfg_t loaded_motor_cfg;
    if (config_store_load_motor_cfg(&loaded_motor_cfg)) {
        g_motor_cfg = loaded_motor_cfg;
        ESP_LOGI(TAG, "Loaded persisted motor cfg from NVS: count=%d esc1_is_left=%d",
                 g_motor_cfg.motor_count, g_motor_cfg.esc1_is_left);
    }

    // Pure in-memory update (rc_input_map isn't touched by io_hardware_init()
    // until later), safe to load this early regardless of ordering.
    rc_input_map_cfg_t loaded_rc_map;
    if (config_store_load_rc_input_map(&loaded_rc_map)) {
        for (int i = 0; i < NUM_RC_CHANNELS; i++) {
            rc_input_map[i] = loaded_rc_map.phys_ch[i];
        }
        ESP_LOGI(TAG, "Loaded persisted RC input map from NVS");
    }

    servo_output_map_cfg_t loaded_servo_map;
    if (config_store_load_servo_output_map(&loaded_servo_map)) {
        if (is_output_permutation(loaded_servo_map.phys_out)) {
            for (int i = 0; i < NUM_RC_CHANNELS; i++) {
                servo_output_map[i] = loaded_servo_map.phys_out[i];
            }
            ESP_LOGI(TAG, "Loaded persisted servo output map from NVS");
        } else {
            ESP_LOGW(TAG, "Persisted servo output map is invalid, using default identity map");
        }
    }

    // After every persisted setting above (pass-through needs the
    // calibration and channel maps), before anything slow. Shared by both
    // boot paths -- setup_mode_run() relies on it having already run.
    io_hardware_init();

    // Checked only after every persisted setting above is loaded into its
    // live global, so setup mode's HTTP API reflects actually-persisted
    // state rather than compiled-in defaults. Runs manual pass-through for
    // the whole window.
    if (setup_mode_requested()) {
        setup_mode_run(); // never returns -- back to flight mode is a physical reset
    }

    // Must run here, in this single-threaded setup phase, before imu_task or
    // airspeed_init() (below) create any task that might call
    // i2c_bus_add_device() -- see i2c_bus.h's threading contract. No longer
    // preceded by a 1s settle delay: the 5s BOOT window above already gives
    // the sensors far longer than that to power up.
    i2c_bus_init();
    i2c_bus_scan(); // bring-up diagnostic -- see i2c_bus.h

    // Create the IMU and GPS tasks, pinned to core 1 -- WiFi's own driver/
    // interrupt handling on the ESP32-S3 is tied to core 0, and an unpinned
    // I2C/UART-polling task landing there under WiFi load can starve the I2C
    // driver's recovery path long enough to trip the interrupt watchdog (see
    // setup_mode.c's identical reasoning; flight mode never runs WiFi, so
    // this can't happen here today, but pin it anyway for the same defensive
    // reason control_task already is).
    BaseType_t result = xTaskCreatePinnedToCore(
        imu_task,
        "imu_task",
        4096,
        NULL,
        5,
        NULL,
        1
    );

    if (result != pdPASS) {
        ESP_LOGE(TAG, "Failed to create IMU task! Error: %d", result);
        return;
    } else {
        ESP_LOGI(TAG, "IMU task created successfully");
    }

    result = xTaskCreatePinnedToCore(
        gps_task,
        "gps_task",
        4096,
        NULL,
        5,
        NULL,
        1
    );

    if (result != pdPASS) {
        ESP_LOGE(TAG, "Failed to create GPS task! Error: %d", result);
        return;
    } else {
        ESP_LOGI(TAG, "GPS task created successfully");
    }

    nav_init();

    // Scaffolding only: this wires up the mutex+task so airspeed_get()/
    // airspeed_reading() are live, but airspeed_enable() is deliberately
    // NOT called here. That should happen from inside the real sensor
    // driver's init, only after it self-validates the hardware is present
    // (mirroring imu_init()'s WHO_AM_I-gated pattern) -- so throttle stays
    // on the known-good hardcoded path until real, validated hardware
    // exists.
    airspeed_init();

    xTaskCreatePinnedToCore(control_task, "control", 8096, NULL, 1, NULL, 1);
    return;
}

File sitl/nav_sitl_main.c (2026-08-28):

#include <math.h>
#include <stdbool.h>
#include <stdio.h>
#include <stdlib.h>
#include <string.h>
#include <time.h>

#include "actuator.h"
#include "airframe_params.h"
#include "gps_math.h"
#include "nav_world.h"
#include "noise.h"
#include "pid.h"
#include "plant.h"

// Mirrors main/include/pwm_output.h's defines (see sitl_main.c)
#define SERVO_MIN_PULSEWIDTH_US 1000
#define SERVO_MAX_PULSEWIDTH_US 2000
#define SERVO_MIN_DEGREE        -90
#define SERVO_MAX_DEGREE        90

// Mirrors main.c/nav.c's own #defines -- see sitl/README.md's note on why
// these live as duplicated constants rather than a shared header: nav.c and
// main.c are FreeRTOS/hardware tasks that can't be linked into a host
// binary directly, the same reason sitl_main.c already reimplements
// control_task's PID/actuator cascade instead of linking main.c.
#define CONTROL_TASK_HZ 100
#define NAV_TASK_HZ 10
#define WAYPOINT_ACCEPTANCE_RADIUS_M 30.0
#define MAX_ROLL_GOAL_DEG 45.0f

#define MAX_WAYPOINTS 16

static float clampf(float v, float lo, float hi)
{
    if (v < lo) return lo;
    if (v > hi) return hi;
    return v;
}

// Computes a waypoint at (bearing_deg, dist_m) from (lat0, lon0), using the
// same equirectangular approximation as distance_to_target()/
// heading_to_target() -- a convenience for sweep testing so scenarios can be
// specified as "45deg right turn, 200m out" instead of hand-picked lat/lon
// pairs that mean nothing to a human reader.
#define EARTH_RADIUS_M (6371000.0)
static void offset_latlon(double lat0, double lon0, float bearing_deg, float dist_m,
                           double *lat_out, double *lon_out)
{
    double bearing_rad = degrees_to_rads(bearing_deg);
    double lat0_rad = degrees_to_rads(lat0);
    *lat_out = lat0 + rads_to_degrees((dist_m * cos(bearing_rad)) / EARTH_RADIUS_M);
    *lon_out = lon0 + rads_to_degrees((dist_m * sin(bearing_rad)) / (EARTH_RADIUS_M * cos(lat0_rad)));
}

int main(int argc, char **argv)
{
    // Heading-loop gains -- default matches nav.c's HEADING_PID_CFG.
    float heading_kp = 1.0f, heading_ki = 0.0f, heading_kd = 0.0f, heading_ilimit = 45.0f;
    // Roll-loop gains -- default matches main.c's ROLL_PID_CFG.
    float roll_kp = 5.0f, roll_ki = 0.0f, roll_kd = 0.4f, roll_ilimit = 250.0f;

    double start_lat = 0.0, start_lon = 0.0;
    float start_heading_deg = 0.0f;
    float airspeed_mps = 12.0f;
    float duration_s = 60.0f;

    // Convenience single-waypoint spec, used when no --wp is given.
    float target_bearing_deg = 90.0f;
    float target_dist_m = 300.0f;

    float roll_noise_deg = 0.0f;
    float heading_noise_deg = 0.0f;
    float servo_rate_dps = 600.0f;
    long seed = 1;

    double wp_lat[MAX_WAYPOINTS], wp_lon[MAX_WAYPOINTS];
    int num_wp = 0;

    for (int i = 1; i < argc; i++) {
        if (strncmp(argv[i], "--heading_kp=", 13) == 0) {
            heading_kp = atof(argv[i] + 13);
        } else if (strncmp(argv[i], "--heading_ki=", 13) == 0) {
            heading_ki = atof(argv[i] + 13);
        } else if (strncmp(argv[i], "--heading_kd=", 13) == 0) {
            heading_kd = atof(argv[i] + 13);
        } else if (strncmp(argv[i], "--heading_ilimit=", 17) == 0) {
            heading_ilimit = atof(argv[i] + 17);
        } else if (strncmp(argv[i], "--roll_kp=", 10) == 0) {
            roll_kp = atof(argv[i] + 10);
        } else if (strncmp(argv[i], "--roll_ki=", 10) == 0) {
            roll_ki = atof(argv[i] + 10);
        } else if (strncmp(argv[i], "--roll_kd=", 10) == 0) {
            roll_kd = atof(argv[i] + 10);
        } else if (strncmp(argv[i], "--roll_ilimit=", 14) == 0) {
            roll_ilimit = atof(argv[i] + 14);
        } else if (strncmp(argv[i], "--start_lat=", 12) == 0) {
            start_lat = atof(argv[i] + 12);
        } else if (strncmp(argv[i], "--start_lon=", 12) == 0) {
            start_lon = atof(argv[i] + 12);
        } else if (strncmp(argv[i], "--heading0=", 11) == 0) {
            start_heading_deg = atof(argv[i] + 11);
        } else if (strncmp(argv[i], "--airspeed=", 11) == 0) {
            airspeed_mps = atof(argv[i] + 11);
        } else if (strncmp(argv[i], "--duration_s=", 13) == 0) {
            duration_s = atof(argv[i] + 13);
        } else if (strncmp(argv[i], "--target_bearing=", 17) == 0) {
            target_bearing_deg = atof(argv[i] + 17);
        } else if (strncmp(argv[i], "--target_dist_m=", 16) == 0) {
            target_dist_m = atof(argv[i] + 16);
        } else if (strncmp(argv[i], "--roll_noise_deg=", 17) == 0) {
            roll_noise_deg = atof(argv[i] + 17);
        } else if (strncmp(argv[i], "--heading_noise_deg=", 20) == 0) {
            heading_noise_deg = atof(argv[i] + 20);
        } else if (strncmp(argv[i], "--servo_rate=", 13) == 0) {
            servo_rate_dps = atof(argv[i] + 13);
        } else if (strncmp(argv[i], "--seed=", 7) == 0) {
            seed = atol(argv[i] + 7);
        } else if (strncmp(argv[i], "--wp=", 5) == 0) {
            if (num_wp >= MAX_WAYPOINTS) {
                fprintf(stderr, "Too many --wp (max %d)\n", MAX_WAYPOINTS);
                return 1;
            }
            if (sscanf(argv[i] + 5, "%lf,%lf", &wp_lat[num_wp], &wp_lon[num_wp]) != 2) {
                fprintf(stderr, "Bad --wp=%s (expected lat,lon)\n", argv[i] + 5);
                return 1;
            }
            num_wp++;
        } else {
            fprintf(stderr, "Unknown arg: %s\n", argv[i]);
            fprintf(stderr, "Usage: %s [--start_lat=deg] [--start_lon=deg] [--heading0=deg] "
                            "[--airspeed=mps] [--duration_s=s] [--target_bearing=deg] "
                            "[--target_dist_m=m] [--wp=lat,lon (repeatable, overrides target_bearing/dist)] "
                            "[--heading_kp=] [--heading_ki=] [--heading_kd=] [--heading_ilimit=] "
                            "[--roll_kp=] [--roll_ki=] [--roll_kd=] [--roll_ilimit=] "
                            "[--roll_noise_deg=] [--heading_noise_deg=] [--servo_rate=deg_per_s] [--seed=n]\n",
                    argv[0]);
            return 1;
        }
    }

    if (num_wp == 0) {
        offset_latlon(start_lat, start_lon, target_bearing_deg, target_dist_m,
                       &wp_lat[0], &wp_lon[0]);
        num_wp = 1;
    }

    srand(seed == 0 ? (unsigned)time(NULL) : (unsigned)seed);

    pid_cfg_t heading_pid = pid_init(heading_kp, heading_ki, heading_kd, heading_ilimit);
    pid_cfg_t roll_pid = pid_init(roll_kp, roll_ki, roll_kd, roll_ilimit);
    plant_state_t plant = plant_init(0.0f);
    actuator_state_t actuator = actuator_init();
    world_state_t world = world_init(start_lat, start_lon, start_heading_deg);

    int wp_idx = 0;
    float goal_roll_deg = 0.0f;

    const float inner_dt_s = 1.0f / CONTROL_TASK_HZ;
    const int nav_divider = CONTROL_TASK_HZ / NAV_TASK_HZ;
    const int steps = (int)(duration_s * CONTROL_TASK_HZ);
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

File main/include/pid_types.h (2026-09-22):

#ifndef PID_TYPES_H
#define PID_TYPES_H

// Shared types for persisted/settable PID gains. Split out from
// config_store.h so both config_store.h (NVS blob format) and nav.h
// (nav_set_heading_pid_gains()'s signature) can include this without a
// circular dependency between the two.
//
// Formerly part of the wire protocol shared with the now-removed ESP-NOW
// basestation link (cl_pid_gains_t etc. in config_link_proto.h) -- kept
// byte-identical (same 4 floats) so existing persisted NVS blobs for
// pid_roll/pid_pitch/pid_hdg/pid_aspd still parse unchanged.

typedef struct {
    float k_p;
    float k_i;
    float k_d;
    float i_limit;
} pid_gains_t;

// Bit N set = the corresponding field in a pid_gains_t is present in this
// update and should overwrite the live value for that one field; bit clear
// = leave that field untouched.
typedef enum {
    PID_FIELD_KP     = 1 << 0,
    PID_FIELD_KI     = 1 << 1,
    PID_FIELD_KD     = 1 << 2,
    PID_FIELD_ILIMIT = 1 << 3,
} pid_field_mask_t;

typedef enum {
    PID_TARGET_ROLL     = 0,
    PID_TARGET_PITCH    = 1,
    PID_TARGET_HEADING  = 2,
    PID_TARGET_AIRSPEED = 3,
} pid_target_t;

#endif // PID_TYPES_H

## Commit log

2026-03-20 initial commit with basic working implementation of servos
2026-03-21 esp32s3 cannot have custom resolutions on capture, so added post capture math to solve for it
2026-03-21 made all creation no longer auto choose index, as it was over complicating for no reason
    [pwm_output.c, pwm_output.h]
2026-03-21 Current setup can switch between manual pass-through and ignore input mode.
2026-03-24 added time to avoid using old pulse widths
    [main.c, rc_capture.c]
2026-03-26 created empty file for imu processing
2026-05-15 added arduino's MadgwickAHRS filter code
2026-05-15 IMU works! roll and pitch are all i need for now!
2026-05-15 added mutex for imu data
2026-05-15 added pid functions (NOT TUNED/SETUP)
2026-05-15 added led for debugging
2026-05-15 removed led stuff. issue was overlappng GPIO
    [imu.c, imu.h, main.c]
2026-05-15 removed extra led stuff
2026-05-16 changed pins imu uses
2026-05-23 copied over gps driver from my other repo
2026-05-23 moved shared imu_data to imu.c/.h instead of main
2026-05-23 updated how PID logic is controlled, and cleaned up some code
2026-07-17 Added airspeed support and generalized i2c pins for chaining
2026-07-29 kicad files
    [fixed-wing-drone.kicad_pcb, fixed-wing-drone.kicad_sch]
2026-08-05 PID changes
2026-08-19 Added support for single flap drones (ones with elevons) and updated PCB
    [fixed-wing-drone.kicad_pcb]
2026-08-19 added kicad history file
2026-08-21 changed pins to the PCB pins
2026-08-23 updated gitignore and tried out some changes to pcb layout
    [fixed-wing-drone.kicad_pcb, fixed-wing-drone.kicad_sch]
2026-08-24 V2 PCB; Fixed pin ordering, changed to mostly smd connectors, added 5v jst gh for lidar & airspeed; and fixed misprints on silkscreen
    [fixed-wing-drone.kicad_pcb, fixed-wing-drone.kicad_sch]
2026-08-25 Reverted to through hole but added new connectors for airspeed and added 5v for powering it. Did other minor revisions like removing some of the extra AUX IO
    [fixed-wing-drone.kicad_pcb, fixed-wing-drone.kicad_sch]
2026-08-26 opened file n now i need to repush
    [fixed-wing-drone.kicad_sch]
2026-08-28 Extend SITL to the waypoint-nav loop; fix roll/pitch PID instability at full authority
    Splits pure lat/lon/bearing math out of gps.c into main/gps_math.c (no
    FreeRTOS/hardware deps) so it can link directly into a new sitl/nav_sim.exe,
    which simulates nav.c's HEADING_PID_CFG cascaded into the roll attitude loop
    via a coordinated-turn world model.
    Sweeping the new sim surfaced a real bug: ROLL_PID_CFG/PITCH_PID_CFG
    (k_p=10, k_d=0.3), previously validated only against small disturbance
    recovery, are unstable under the full-authority steps set_goal_roll_deg/
    set_goal_pitch_deg's clamps allow -- which the new nav_task actually
    commands in normal operation. Re-swept across the entire commanded ra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
    [gps.c, main.c, nav.c]
2026-08-28 Add wireless ESP-NOW config link, basestation companion device, sensor sim mode
    Lets waypoints and PID gains be pushed to the FC in the field without
    reflashing over USB. The FC's ESP-NOW receiver only opens on the ground with
    idle throttle and low GPS groundspeed (30s debounce to re-open after a
    close, immediate open at boot), closing instantly otherwise, so it can't be
    listening mid-flight. A separate basestation project hosts its own AP + a
    phone-friendly map UI, tracks pending/confirmed/failed status per field
    since the FC link isn't always reachable, and only ever sends the fields a
    user actually touched.
    Also adds a per-sensor (IMU/GPS/airspeed) simulated-data mode for bench
    testing t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
    [partitions.csv]
2026-08-30 Add a persisted SITL regression suite (80 scenarios)
    sitl/tests/run_tests.py replaces one-off ad-hoc sweep scripts with a
    saved suite: 24 attitude scenarios (sitl_sim.exe: clean step response
    + noise robustness, roll and pitch) and 56 nav scenarios (nav_sim.exe:
    8x4 bearing/distance grid, noise robustness, 180deg reversal,
    immediate-arrival waypoint, a 3-waypoint mission, and a square 80m
    mission exercising four consecutive turns). All run against the
    current firmware gains as a regression check, not a gain search.
    Added a "Result:" summary line to sitl_sim.exe (max_abs_angle_deg,
    final_error_deg, settle_time_s, diverged) mirroring nav_sim.exe's
    existing convention, so the runner only parse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
    [sitl_main.c]
2026-09-12 PCB v3.0
    [aux.kicad_sch, barometer.kicad_sch, esc_io.kicad_sch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]
2026-09-12 Fix ESP32 LDO thermal margin, add USB-C/SBUS ESD protection
    Design review flagged the ESP32-S3's 3.3V LDO (AP2112K-3.3, SOT-23-5)
    at only 1.5C margin to absolute max under WiFi load. Swapped to a
    Torex XC6220B331PR-G (SOT-89-5, thermal tab tied to GND) with matching
    input/output caps and thermal vias under the tab; thermal score is now
    100/100 with no findings. Sensor LDO (U6) was unaffected and left as-is.
    Also added TVS protection that was missing on two exposed signal paths:
    D4 + bulk cap on USB-C VBUS (J13, now populated for field use) ahead of
    the existing blocking diode, and a matching TVS (D6) on the RC receiver
    SBUS line (J7), reusing the same part to minimize BOM diversity.
    Every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
    [aux.kicad_sch, barometer.kicad_sch, esc_io.kicad_sch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]
2026-09-12 Regenerate fab package after PCB/schematic sync
    Update PCB from Schematic was re-run and the production/ fab package
    regenerated (v3.1) to pick up D4/D6's real part number and the rest of
    this session's rework. Verified clean: kicad-cli DRC reports 0
    violations, 0 unconnected items, 0 schematic-parity mismatches; the
    regenerated BOM confirms U4/D4/D6/C17-C19 are all present with correct
    footprints and LCSC part numbers. production/ itself stays gitignored
    (regeneratable build output, same convention as analysis/).
    Claude-Session: https://claude.ai/code/session_01NksRnW4jXLWsYwZNR7u39H
2026-09-22 removed basestation code and v3.1 of fc pcb
    [aux.kicad_sch, barometer.kicad_sch, esc_io.kicad_sch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]
2026-09-22 moved basestation to setup mode, and started mission board pcb
    [camera.kicad_sch, esp32_core.kicad_sch, expander_mux.kicad_sch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]
2026-09-24 pcb progress
    [camera.kicad_sch, esp32_core.kicad_sch, esp32s3.kicad_sch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]
2026-10-02 code for PCB v2.1 seems to be completed
2026-10-02 progress on v1 of mission board
    [camera.kicad_sch, esp32_core.kicad_sch, expander_mux.kicad_sch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]
2026-10-08 Kicad FC v3.1 complete, Mission Controller and UWB boards v1 complete, firmware v2 complete!
    [aux.kicad_sch, camera.kicad_sch, esc_io.kicad_sch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]
